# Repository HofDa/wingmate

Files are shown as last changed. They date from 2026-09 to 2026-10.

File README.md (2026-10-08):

# Bee × Fly Connectome MVP

Lokaler Forschungsprototyp für Wildbienen-ID aus **Wing Interference Patterns (WIP)** und **Flügeladerung**.

**Benutzerhandbuch:** [docs/Benutzerhandbuch.md](docs/Benutzerhandbuch.md) – Bedienung Schritt für Schritt, Rig, Landmarken, Training, Fehlerbehebung.
**Modellentwicklung:** [docs/model-development.md](docs/model-development.md) – tierbasierte Auswertung, Distanzkalibrierung und unabhängige Tests.
**Optionales Startmodell:** [models/bombus-starter/README.md](models/bombus-starter/README.md) – Landmarken-LDA für drei Bombus-Arten, numerische Referenzdaten und ODbL-Zitation.
**Aufnahme-Rig zum Drucken:** [rig/README.md](rig/README.md) – parametrisches OpenSCAD-Modell, STL, Teileliste, Montage.

## Pipeline

1. Venationsbild und optional WIP desselben Vorderflügels, mit dokumentierter QC
2. Flügelmerkmale und optionale manuelle Landmarken im passenden anatomischen Schema
3. Ein Referenzprototyp pro Tier aus seinen unterschiedlichen Flügelansichten
4. Standard: Procrustes/PCA/LDA mit Landmarken, sonst Distanz-kNN auf standardisierten Merkmalen
5. Separate Tier-Kalibrierung anhand von Merkmalsdistanzen; live nur explorative Typikalität
6. Cosine-kNN, FlyHash und Random Walk als Entwicklungsvergleiche
7. Abschlusstest an unabhängigen Tieren und ungesehenen Taxa außerhalb der Entwicklung

## Start

Für ES-Module und Web Worker einen lokalen HTTP-Server im Projektordner starten:

```bash
python -m http.server 8000
```

Dann `http://localhost:8000` öffnen.

## GitHub Pages

Die veröffentlichte App: **https://hofda.github.io/wingmate/**.

Der Workflow `.github/workflows/pages.yml` testet bei jedem Push auf `master` die Anwendung, erstellt das statische `_site`-Artefakt und veröffentlicht es über GitHub Pages. In den Repository-Einstellungen ist **Pages → Source → GitHub Actions** erforderlich. Der Workflow kann auch manuell gestartet werden.

`npm run build:pages` erstellt das Artefakt lokal in einem leeren `_site`-Verzeichnis. Es enthält die Laufzeitdateien und Icons; Testdatensätze, Entwicklerwerkzeuge und lokale Zertifikate werden nicht als Website veröffentlicht. Die Service-Worker-Version wird aus dem Inhalt des Artefakts erzeugt, damit geänderte Deployments automatisch einen neuen Offline-Cache erhalten. `PWA_SITE_ROOT=_site node scripts/pwa-smoke.cjs` prüft das fertige Artefakt inklusive Unterverzeichnis-Hosting und Offline-Nutzung.

Die Online-App speichert ihre Referenzen und Exemplare separat von `localhost`, da Browserspeicher an die Herkunft gebunden ist. Referenzen bei Bedarf lokal exportieren und in der veröffentlichten App importieren.

Für das **Smartphone** (Kamera braucht HTTPS) im selben WLAN:

```bash
npm run serve:https     # druckt https://<LAN-IP>:8443; Zertifikatswarnung einmal bestätigen
```

## Bedienung

Die App hat vier Bereiche (unten am Handy, oben am Desktop):

- **Exemplar** – Venation (und optional WIP) per **Foto wählen** (am Handy: Kamera oder Galerie)
  oder **Live-Kamera** laden, dann unter **Prüfen & Landmarken** Maske und Orientierung prüfen
  (*Um 180° drehen*, *Spiegeln*, *Standard geprüft*) und Landmarken setzen. Seltenes liegt
  eingeklappt unter *Maske korrigieren*, *Export & Metadaten* und *Weitere Aktionen*.
- **Ergebnis** – Bestimmung (Ähnlichkeitsgraph, Procrustes + LDA, offene Menge); Einbettung und
  Random Walk eingeklappt.
- **Referenzen** – Sammlung (Export/Import), Live-Prüfung und **Modell trainieren**.
- **Einstellungen** – Aufnahme-Rig, Rechenraum/FlyWire, App-Installation, Methodik.

Die Leiste am unteren Rand zeigt für das aktuelle Exemplar den Stand (Bild · Geprüft · Landmarken)
und genau den nächsten Schritt: **Freigeben**, danach **Bestimmen** oder **Als Referenz …**
(Art, Exemplar-ID, Geschlecht, Serie/Fundort).

## Als PWA installieren und offline nutzen

Die App enthält ein Web-App-Manifest, Installationsicons und einen Service Worker. Nach dem ersten vollständigen Online-Aufruf meldet die Leiste **Offline bereit**. Danach funktionieren App-Start, lokale Bildverarbeitung, Klassifikation und Markov-Walks auch ohne Netzwerk. Referenzen bleiben im bestehenden `localStorage`, archivierte Exemplare in IndexedDB. Die Installation migriert keine Daten zwischen Browsern oder Geräten; Referenzen weiterhin regelmäßig exportieren.

- Desktop/Android: **App installieren** anklicken, sobald der Browser die Installation anbietet; alternativ das Browsermenü verwenden.
- iPhone/iPad: **Teilen → Zum Home-Bildschirm** verwenden.
- Für Geräte im Netzwerk und öffentliche Bereitstellung **HTTPS** verwenden. `http://localhost:8000` genügt für lokale Entwicklung; eine unverschlüsselte LAN-IP genügt nicht für den Service Worker.
- Die Dateien können ohne Build-Schritt auch in einem Unterverzeichnis bereitgestellt werden. Manifest, Start-URL und Cache sind relativ zum App-Verzeichnis.

Neue Versionen werden im Hintergrund vollständig geladen. **Update laden** aktiviert die neue Version und lädt die Seite neu; vorher ungespeicherte Arbeit sichern. Ohne diesen Klick wartet ein Update, bis alle App-Fenster geschlossen sind. Gespeicherte Referenzen und Exemplare werden bei Updates nicht gelöscht. Nur die aufgelisteten App-Dateien werden gecacht; große Testdaten und importierte Graphdateien sind nicht Teil des Offline-Caches. Importierte Graphen und ungespeicherte Bilder müssen nach einem Neustart wie bisher erneut geladen werden.

Bei Änderungen an App-Dateien die `VERSION` in `sw.js` erhöhen und die vollständige Anwendung gemeinsam veröffentlichen. Neue Laufzeitmodule in `APP_FILES` aufnehmen. `sw.js` sollte vom Hosting ohne langfristigen HTTP-Cache ausgeliefert werden.

Prüfungen: `npm test`; mit installiertem Playwright und Chrome zusätzlich `node scripts/pwa-smoke.cjs` für Installierbarkeit, Offline-Reload, Worker, lokale Speicherung, Updates und Hosting im Unterverzeichnis. `node scripts/generate-pwa-icons.cjs` erzeugt die PNG-Icons aus `icons/wing.svg` erneut. Beide Browser-Skripte unterstützen `CHROME_PATH` für einen anderen Chrome-Pfad.

Installationsvoraussetzungen: [MDN – Making PWAs installable](https://developer.mozilla.org/en-US/docs/Web/Progressive_web_apps/Guides/Making_PWAs_installable).

Alle Bilder und Referenzen bleiben lokal. Referenzen werden im Browser-`localStorage` gespeichert und können als JSON exportiert werden.

Nach einer Klassifikation erklärt **Wie entsteht das Ergebnis? · Markov-Kette** die Berechnung. Mit **Abspielen**, **Zurück**, **Weiter**, **Zum Start**, **Zum Ergebnis** und dem Schrittregler lassen sich die Schritte 0–40 untersuchen. Drei Kennzahlen zeigen die Wahrscheinlichkeit beim eigenen Exemplar, bei den Referenzen und den seit dem letzten Schritt verschobenen Anteil. Die Artentabelle trennt die rohe Wahrscheinlichkeit von den nach Referenzzahl ausgeglichenen Ähnlichkeitsscores; die Scores des letzten Schritts entsprechen den Random-Walk-Balken im Ergebnis.

Im Graphen bleiben Positionen und Farben während der Wiedergabe gleich. Ein Klick auf einen Knoten (oder Tab und Enter) zeigt seine Übergangschancen einschließlich des 20-%-Rücksprungs. **Beispielpfad anzeigen** schaltet einen reproduzierbaren simulierten Weg ein: Orange zeigt den Weg, gestrichelt einen Rücksprung. Dieser einzelne Weg bestimmt nicht die berechnete Verteilung. Bei großen Sammlungen zeigt der Graph bis zu 25 Knoten am Desktop bzw. 13 auf schmalen Ansichten; **Alle Knoten · genaue Werte** enthält sämtliche Knoten, Wahrscheinlichkeiten und Änderungen in Prozentpunkten. Änderungen an Eingaben, Referenzen oder Reservoir-Einstellungen setzen die Ansicht zurück. Dargestellt wird der Klassifikationsgraph, nicht die interne FlyWire-Propagation.

## Step 0 · Smartphone-Aufnahme & Rig (rig-profile-1)

**Live-Kamera** an einem Bildfeld (`imaging/camera.js`) nimmt direkt mit der Rückkamera auf: Live-Vorschau mit
Platzierungsrahmen (Basis links, Spitze rechts, anterior oben), Fokus-, Überbelichtungs- und
Rig-Abweichungsanzeige, Mittelung über 1–16 Frames (Rauschen ∝ 1/√N) und verlustfreie PNG-Übergabe
an die QC. Aufnahmemetadaten (Frames, Rauschen, Kameraeinstellungen, Rig-ID) werden mitarchiviert.

- **Android + Chrome:** Fokus, Belichtung, Weißabgleich, ISO, Zoom und Taschenlampe werden – soweit
  die Kamera sie anbietet – nach dem Einpendeln mit **Aktuelle Einstellungen fixieren** gesperrt, im
  Rig gespeichert und beim nächsten Start automatisch mit exakt derselben Auflösung wieder angewendet.
- **iPhone (Safari):** Web-Seiten erhalten keine manuelle Kamerasteuerung. Live-Aufnahme funktioniert,
  aber mit Automatik; alternativ **Foto wählen** → Kamera-App (volle Auflösung, dort AE/AF-Sperre
  durch langes Tippen). Die Driftprüfung meldet dann abweichende Belichtung. iOS wechselt im
  Nahbereich teils automatisch das Objektiv; das verändert Maßstab und Licht – Profil erkennt das
  nur über Drift/Größe, daher Makro-Vorsatz fest auf die Hauptkamera.

### Rig kalibrieren

Unter **Rig kalibrieren** im Live-Kamera-Bereich (oder *Einstellungen → Mit der Live-Kamera kalibrieren*), mit montiertem Rig, eingeschaltetem Licht und fixierter Kamera:

1. **Venation-Hintergrund** – leerer Objektträger im Durchlicht (16 Frames gemittelt).
2. **WIP-Hintergrund** – leer, schwarzer Hintergrund, Auflicht.
3. **WIP-Graukarte** (optional) – neutrale Graukarte an der Flügelposition, Auflicht.
4. **Maßstab** (optional) – Lineal/Objektmikrometer an der Flügelposition, zwei Punkte anklicken, mm eingeben.

Das Profil (`imaging/rig.js`, IndexedDB, als JSON export-/importierbar) wird angewendet, wenn die
Bildgröße exakt passt; sonst verarbeitet die QC ohne Korrektur und sagt warum. Mit Profil:

- **Flat-Field-Korrektur** `out = in × Ziel / Beleuchtung(x,y,Kanal)` aus dem geglätteten leeren
  Durchlichtbild bzw. der Graukarte: entfernt Vignettierung, ungleichmäßiges Licht und Farbstich
  (Referenz wird neutralgrau). Gesättigte Sensorwerte bleiben gesättigt. Die Originaldatei wird
  unverändert archiviert; die Korrektur steht in `radiometricCorrection`.
- **Hintergrundmodell pro Pixel** für die Segmentierung statt einer Randfarbe; statischer Staub auf
  Glas/Diffusor hebt sich auf, die Schwelle folgt dem gemessenen Rauschen.
- **Driftprüfung** (Randband gegen Profil): verschobenes Rig oder anderes Licht → REVIEW und
  Rückfall auf die Randfarben-Segmentierung statt eines stillen Fehlers.
- **Absolute Größe**: Mit Maßstab und ohne Randkontakt speichert `metricSize` Flügellänge (mm) und
  -fläche (mm²); der Klassifikator nutzt sie als Block `size` (log), sobald alle Referenzen sie haben.
  Die Normalisierung auf 1024 × 512 entfernt Größe weiterhin.
- Unabhängig vom Rig: Sättigung im Flügel (> 0,5 %) → REVIEW; Schärfe (Laplace-Varianz) wird gespeichert.

In einer synthetischen Prüfung (starke Vignettierung, Farbstich, Staubfleck am Flügelrand) steigt die
Masken-IoU mit Profil auf > 0,95 und liegt deutlich über der Randfarben-Segmentierung
(`tests/rig.test.js`). Das ist ein Modelltest, keine Validierung an echten Rig-Aufnahmen.

### Hinweise für den Aufsatz

- Flügel flach zwischen Objektträger und Deckglas (ein Tropfen 70 % Ethanol hilft beim Glätten) in
  einem festen Schlitz auf Fokusebene; Aufnahme immer derselben Seite bzw. Spiegelung in der QC.
- Venation: gleichmäßiges, diffuses Durchlicht (LED-Panel + Opal-Diffusor), Konstantstrom-LEDs ohne
  PWM – PWM erzeugt mit dem Rolling Shutter Streifen, die keine Flat-Field-Korrektur entfernt.
- WIP: lichtschluckender schwarzer Untergrund (Velours/Flock), Auflicht unter festem Winkel; WIP-Farben
  hängen von Licht- und Blickwinkel ab, daher beides mechanisch fixieren. Gehäuse geschlossen halten,
  damit kein Umgebungslicht einfällt.
- Hohe Farbwiedergabe (CRI ≥ 90) und nach Wechsel von Lampe, Diffusor, Vorsatzlinse oder Telefon
  neu kalibrieren. Die Rig-Abweichung in der Vorschau zeigt, wann das nötig ist.

## Landmarken setzen (Procrustes + LDA)

In der QC-Karte des Venation-Bildes (ohne Venation: WIP) öffnet **Landmarken** den Editor
(`imaging/landmark-ui.js`, Schema/Koordinaten in `classifier/landmarks.js`):

- **Tippen/Klicken** setzt die aktuelle Landmarke und springt zur nächsten offenen. Ein Punkt wird
  nur verschoben, wenn man ihn *zieht* – so lassen sich eng benachbarte Landmarken (1/2, 16/17)
  setzen. Ein Klick auf einen anderen Punkt wählt ihn aus.
- **Lupe**: zeigt die *Originalpixel* (volle Kameraauflösung) in Standardorientierung, 6-fach.
  Ein Klick dort verfeinert die gewählte Landmarke und geht weiter – grob tippen, fein setzen,
  auch am Handy. Pfeiltasten verschieben um 0,25 px (Shift: 2 px), `n`/`p` wechseln, Strg+Z.
- **Führung**: Übersicht des mittleren Musters mit der aktuellen Nummer. Ab 2 Punkten wird es an
  die gesetzten Punkte angepasst und zeigt gestrichelt, wo die nächsten erwartet werden. Ab 4
  Punkten werden starke Abweichungen orange markiert (typisch: vertauschte Nummern).
- **Fehlt (beschädigt)** markiert eine nicht bestimmbare Landmarke; unvollständige Sätze gehen
  nicht in die Klassifikation ein.
- Gespeichert wird in **Originalpixeln**; die Punkte bleiben bei Drehen/Spiegeln/Schwelle/Neuberechnung
  gültig. Ins Archiv (IndexedDB), in den JSON-Export und als **Landmarken als CSV** (*Weitere Aktionen*)
  (`file,x1,y1,…`, y nach unten; `landmarksCsv(…, {yUp: true})` für die Konvention des Datensatzes)
  für MorphoJ/geomorph. Änderungen nach **Freigeben** heben die Freigabe auf.

**Schema** `bombus-19`: die 19 Landmarken des Molasy-&-Tofilski-Datensatzes (IdentiFly-Nummerierung).
Die Führung ist das Procrustes-Mittel aller 814 Flügel, nachgerechnet in `tests/landmarks.test.js`.
Achtung: die CSV des Datensatzes zählt **y von unten** (auf den 18 lokalen Bildern liegen die Punkte
nur so auf Aderkreuzungen). Für Gattungen mit anderer Aderung (z. B. 2 Submarginalzellen) ist ein
eigenes Schema nötig; Blöcke verschiedener Schemata werden nie verglichen.

**Klassifikation**: Vollständige Landmarken eines *orientierungsbestätigten* Bildes werden zum Block
`landmarks` (Standardansicht, damit linke und rechte Flügel nach dem Spiegeln vergleichbar sind –
Procrustes entfernt keine Spiegelung). Haben alle Referenzen Landmarken desselben Schemas, zeigt die
Ausgabe zusätzlich **Procrustes + LDA**: GPA (nur auf Trainingsreferenzen; Abfrage an feste Mittelform angepasst) → Hauptkomponenten
(bei wenigen Exemplaren höchstens (n − Taxa)/2) → LDA mit Ledoit–Wolf-Schrumpfung →
Wahrscheinlichkeiten per gruppiertem Leave-one-out **temperaturkalibriert**. Die Validierung listet
die LDA-Zeile zuerst. LDA wählt immer ein bekanntes Taxon; für Unbekannte gilt das konforme Set.

Die Temperatur wird nur aus den Trainingsgruppen geschätzt. Auch in dieser inneren
Validierung wird die Procrustes-Ausrichtung neu angepasst. Entwicklungswerte ersetzen
keinen Test an unabhängigen Tieren oder eine Prüfung der Erkennung unbekannter Arten.

## Training (Modell einfrieren)

Unter **Referenzen → Modell trainieren** (`classifier/model.js`, läuft im Worker):

1. **Bereitschaft** je Art: Exemplare, Flügel, Landmarken, Geschlecht, Serien; Warnung bei
   < 10 Exemplaren, nur einem Geschlecht oder nur einer Serie/Fundort.
2. **Trainieren** reserviert je Taxon standardmäßig 20 % der unabhängigen Tiere für die
   Kalibrierung (mindestens zwei Tiere bleiben im Training). Diese Tiere beeinflussen keine
   Anpassung von Ausrichtung, Standardisierung, PCA oder LDA. Ein fester FlyHash lernt keine
   Bildmerkmale. Fehlende Modalitäten erfordern eine explizite Wahl des Eingabemodus.
3. **Bewertung** aller Verfahren mit denselben stratifizierten, nach Exemplar gruppierten
   5 Falten, mit neu angepasster Pipeline pro Trainingsfold. Landmarken-LDA ist Standard,
   sonst Distanz-kNN; andere Verfahren bleiben Vergleiche. Jedes Tier zählt einmal, Flügelwerte
   stehen getrennt im Export. Die Intervalle resampeln Tiere. Das sind Entwicklungswerte, kein unabhängiger Abschlusstest. Haben alle Referenzen eine Serie,
   zusätzlich **Transfer auf ungesehene Serien** (jeweils eine Serie zurückgehalten).
4. Das Modell wird gespeichert (IndexedDB), ist exportier-/importierbar (`wingmate-model-3`,
   JSON) und bestimmt, solange aktiv, alle neuen Tiere; neue Flügel richtet es per Procrustes an
   der gespeicherten Mittelform aus. Geänderte Referenzen werden angezeigt – dann neu trainieren.

Serien/Geschlecht müssen die spätere Anwendung abdecken. Stabile Exemplar-IDs sind Pflicht,
damit linke/rechte Flügel eines Tieres im selben Split bleiben. Alte Modelle benötigen neues
Training. Bildreferenzen aus `wing-features-1` / `wing-normalizer-0.2` müssen aus den archivierten
Originalen neu verarbeitet werden; Dateien und Archive werden nicht gelöscht.

## Echte FlyWire-Daten

Codex bietet für FlyWire-FAFB öffentliche Daten-Downloads und exportierbare Connectivity-Tabellen. Für den Browser sollte nicht das komplette Netzwerk geladen werden, sondern ein Subgraph (z. B. Mushroom Body / Kenyon-cell-bezogene Zellen).

1. Connectivity-CSV aus Codex/FlyWire exportieren.
2. Falls gewünscht, zusätzlich eine Liste erlaubter Root IDs erstellen.
3. CSV kompakt konvertieren:

```bash
python prepare_flywire.py connections.csv flywire-subgraph.json \
  --source-col pre_root_id \
  --target-col post_root_id \
  --weight-col syn_count \
  --min-weight 5 \
  --max-nodes 20000 \
  --max-edges 150000
```

Falls die CSV andere Spaltennamen verwendet, diese per `--source-col`, `--target-col`, `--weight-col` angeben.

Danach `flywire-subgraph.json` im UI unter **FlyWire-Subgraph importieren** laden.

## Step 2 · Klassifikation (wing-features-2)

Code in `classifier/` (reine ES-Module, in Node getestet), UI in `app.js`, Markov-Ansicht in `walk.js`.

1. **Merkmale** (`features.js`) auf dem auf 256 × 128 verkleinerten Normalbild, mit separater
   Innenmaske gegen interpolierte Konturränder. Gleichförmige Membranen erzeugen keine Adermerkmale:
   Umrissprofil (66), Venation als HOG-artige Orientierungshistogramme + relative Dunkelheit
   je 8 × 4-Zelle ohne Konturrand (288), WIP als CIELAB je Zelle + chroma-gewichtetes
   Farbtonhistogramm (112). Keine Farbkorrektur; Aufnahmebedingungen müssen fix sein.
2. **Standardisierung** auf einem Prototyp je Trainingstier (z-Score, jeder Block gleich gewichtet).
   Identische Wiederholungen werden entfernt, unterschiedliche Ansichten innerhalb eines Tieres gemittelt.
   Referenzen speichern **Merkmale, keine Embeddings**; bei jeder Klassifikation wird
   alles mit denselben Einstellungen neu eingebettet (alte v1-Embedding-Referenzen werden
   erkannt und nicht verwendet).
3. **Reservoir** (`embedding.js`): FlyHash nach Dasgupta et al. 2017 (zentrieren, dünne
   *binäre* Projektion mit Fan-in 6, Top-5 %-Winner-take-all), dichte Zufallsprojektion als
   LSH-Kontrolle, „kein Reservoir“, optional FlyWire-Graph (explorativ: Merkmal→Neuron-
   Zuordnung ist willkürlich).
4. **Random Walk with Restart** auf dem kNN-Graphen (k = 7, Restart 0,2, 40 Schritte).
   Die Masse je Taxon wird durch dessen Referenzzahl geteilt, sonst gewinnt das häufigste
   Taxon. `rwrTransitions` liefert dieselbe Übergangsmatrix an die Markov-Ansicht; ein Test
   prüft, dass `traceWalk` exakt die bewertete Verteilung reproduziert.
5. **Open-set** im eingefrorenen Modell: label-bedingte Split-Kalibrierung gegen getrennte
   Tiere. Der Score misst euklidische Distanzen in den standardisierten Merkmalen ohne
   L2-Normalisierung; damit bleiben extreme Abweichungen entlang bekannter Richtungen sichtbar.
   Mehrere Flügel eines Kalibrierungstieres ergeben nur einen (maximalen) Score; auch die
   Nachbarschaft zählt Tiere, nicht doppelte Flügel. Bei ε = 0,1 sind mindestens neun unabhängige
   **Kalibrierungstiere je Taxon** für die nötige p-Wert-Auflösung erforderlich. Darunter meldet
   die UI unzureichende Kalibrierung. Live-Jackknife bleibt ausdrücklich explorativ und darf keine
   kalibrierte Abdeckung oder belastbare Erkennung unbekannter Arten behaupten.
6. **Validierung** im UI: gruppierte Kreuzvalidierung mit vollständiger Anpassung innerhalb der
   Trainingsgruppen, aktueller Modus gegen kNN und „kein Reservoir“. Bilderpaare erfordern eine
   Bestätigung desselben Flügels und der inneren Korrespondenz. QC-Hinweise benötigen eine
   dokumentierte Freigabebegründung; ein plausibler Umriss allein belegt keine brauchbare Aderung.

### Benchmark auf realen Daten

`node scripts/landmark-benchmark.js --out test-data/landmark-benchmark.json` nutzt
814 Landmarkdatensätze (423 Exemplare, 3 *Bombus*-Arten). Version 3 prüft die
**Klassifikationsstufe** mit Tierprototypen, Tierergebnissen und Bootstrap-Intervallen in
identischen fünf gruppierten Folds, getrennter Tier-Kalibrierung und
Procrustes/Skalierung/PCA/LDA ausschließlich im Trainingsfold. Die innere Temperaturkalibrierung
hält ebenfalls ganze Tiere zurück und passt die Ausrichtung neu an.

Die frühere Tabelle mit globaler Procrustes-/z-Score-Anpassung wurde entfernt. Die aktuellen
Messwerte und das genaue Protokoll stehen in `test-data/landmark-benchmark.json`. Sie belegen
keine Genauigkeit der vollständigen Bildpipeline und keinen Nutzen echter gepaarter Bee-WIP-Daten.
Der [Auditbericht](docs/pipeline-audit.md) dokumentiert die verbleibenden Daten- und Forschungsaufgaben.

### Tests

```bash
npm test                                           # Node: Normalisierung, Klassifikation, Walk
NODE_PATH=… node scripts/markov-ui-e2e.cjs        # Browser: Markov-Anzeige, Daten, Steuerung, Desktop/Handy
NODE_PATH=… node scripts/classifier-e2e.cjs        # Browser: QC → Referenzen → Klassifikation → Walk → Validierung
NODE_PATH=… node scripts/camera-e2e.cjs            # Browser, Fake-Kamera: Rig kalibrieren → Neustart → Aufnahme → QC
NODE_PATH=… node scripts/landmark-e2e.cjs          # Browser, 7 reale Flügel: 19 Landmarken per UI, Lupe, LDA, CSV
NODE_PATH=… node scripts/training-e2e.cjs          # Browser: Training im Worker, Bericht, Modell bestimmen, Export/Import
```

Der Landmarken-E2E klickt die publizierten Landmarken durch die Oberfläche, prüft den exakten
Koordinatenweg (Klick → Standardansicht → Originalpixel, auch mit Flip/Mirror), dass die Punkte
auf Aderkreuzungen des angezeigten Bildes liegen, sowie LDA-Ergebnis, Validierung und CSV-Export.
Er misst nicht, wie genau ein Mensch klickt.

Der Klassifikations-E2E prüft Verdrahtung und Konsistenz auf den Entwicklungsbildern, keine
Genauigkeit. Der Kamera-E2E erzeugt synthetische Y4M-Videos (leeres Rig / Rig mit Flügel inkl.
Vignettierung, Farbstich, Rauschen) und prüft Flat-Field, Hintergrundmodell, Drift, Masken-IoU > 0,95
und die mm-Länge. Beide brauchen einen Server auf `127.0.0.1:8000`.

## Was noch nicht „Publikationsniveau“ ist

- Die WIP- und Aderungsfeatures sind bewusst leichtgewichtig und interpretierbar. Für ernsthafte Taxonomie sollten CNN/ViT-Embeddings bzw. automatische Landmark-Erkennung ergänzt werden.
- Das eingefrorene Modell nutzt getrennte Kalibrierungstiere; die Live-Bestimmung bleibt heuristisch. Die Erkennung unbekannter Arten braucht einen separaten Test mit zurückgehaltenen Taxa.
- Die Mushroom-Body-Variante ist biologisch inspiriert; nur der importierte Graph verwendet reale FlyWire-Konnektivität.
- Vor einer wissenschaftlichen Aussage muss gegen starke Baselines verglichen werden: Procrustes+LDA/SVM, kNN, direkte CNN/ViT-Klassifikation, randomisiertes Reservoir und randomisierte FlyWire-Topologie.

## Sinnvoller erster Datensatz

Für einen Proof of Concept eher 5–10 gut abgesicherte Arten, mehrere Individuen pro Art, standardisierte WIP-Aufnahme und Durchlichtaufnahme desselben Flügels. Danach schwierige Artgruppen hinzufügen.

## Step 1 · Flügelnormalisierung (wing-normalizer-0.3)

Start jetzt **über HTTP**, da ES-Module und Web Worker verwendet werden:

```bash
npm run serve
# http://localhost:8000
npm test
```

Venation und/oder WIP hineinziehen. Die QC zeigt Original, echte Binärmaske,
normalisiertes Bild und Kontur/PCA/Schwerpunkt/Basis-/Spitzenkandidaten.
*Um 180° drehen* und *Spiegeln* korrigieren die Orientierung. Originalseite separat
angeben; vor *Freigeben* bestätigen: Basis links, Spitze rechts, Vorderrand oben.
Schwelle ändern oder eine extern korrigierte Schwarzweißmaske importieren,
wenn die automatische Segmentierung nicht ausreicht. `Reset` verwirft die
Korrekturen, erhält aber die dokumentierte Originalseite.

*Freigeben* archiviert Originaldateien, Masken, normalisierte RGBA-Bilder und
Metadaten lokal in IndexedDB. `Letztes Exemplar öffnen` lädt sie erneut zur QC.
PNG- und JSON-Exporte sind portable Ergebnisse; Browserdaten können vom Benutzer
oder Browser gelöscht werden. JSON enthält auch die Analysemaske als binäre
Lauflängencodierung (beginnt mit Anzahl der Nullen). Feature-Referenzen enthalten
die Vorverarbeitungsversion, Transformationen und Archiv-ID. Alte Referenzen
werden nicht automatisch mit neuen Koordinaten verglichen.

### Verfahren und Koordinaten

- Deterministische Segmentierung auf höchstens 640 px langer Analyseachse:
  dominante Randfarbe, RGB-Abstand, morphologisches Schließen, Lochfüllung,
  größte plausible längliche Komponente. Keine rechteckige Ersatzmaske.
- PCA bestimmt die Längsachse; ein Querschnittsbreitenprofil vergleicht beide
  Enden. Dies ist eine **ungeprüfte Heuristik**, keine anatomische Garantie.
  `orientationConfidence` und `maskConfidence` sind Kategorien, keine
  statistischen Wahrscheinlichkeiten. Symmetrische/abgeschnittene Flügel prüfen.
- Standardcanvas 1024 × 512, mindestens 32 px Rand, Maskenschwerpunkt exakt bei
  (511.5, 255.5). Einheitliche Skalierung ohne Stretching. Die ausgewählte
  Analyseauflösung begrenzt die Konturgenauigkeit; Original-RGB bleibt erhalten.
- Matrizen: zeilenweise 3 × 3, Spaltenvektor `[x,y,1]`. Pixelzentren liegen bei
  ganzzahligen Koordinaten; Originalkoordinaten beziehen sich auf das durch den
  Browser decodierte, EXIF-orientierte Bild. `inverseTransformMatrix` führt zurück.
- RGB wird einmal direkt aus dem Original bilinear resampelt, die Maske per
  nearest-neighbor. Außerhalb der Maske ist Alpha 0. Keine Farbverbesserung,
  Weißabgleich, Histogrammänderung oder WIP-Klassifikation. Browser-Decodierung
  ist keine kontrollierte wissenschaftliche Farbkalibrierung; Originaldateien
  werden unverändert archiviert.
- `scale` ist Pixelnormalisierung, keine Körpergröße. `originalMetricScale`
  bleibt separat und standardmäßig `null`; die API kann z. B.
  `{micrometersPerPixel: 2.5, source: 'stage micrometer'}` erhalten.
- Flächen/Bounding Box in `maskQuality` sind ausdrücklich Analysepixel;
  `wingAreaOriginalPixels` rechnet die Fläche zurück. Originalmaße, Randkontakt,
  Fragmentierung, effektive Parameter und Version werden gespeichert.
- WIP wird über binäre Flügelform auf die normalisierte Venation registriert:
  begrenzte Rotation, uniforme Skalierung und Translation, keine Scherung oder
  nichtlineare Verformung. Registrierung speichert ihre eigene Matrix und die
  zusammengesetzte Original→Referenz-Matrix. Referenz und Moving müssen dasselbe
  Individuum und denselben Vorderflügel zeigen. Eine hohe Mask-IoU belegt keine
  genaue Übereinstimmung innerer Ader-Landmarks.

Die Rechenlogik liegt in `imaging/{segmentation,quality,orientation,normalization,
registration,pipeline,matrix}.js`, der Worker in `worker.js`, UI und Speicherung
in `qc-ui.js` / `storage.js`. Reservoir, FlyWire und Random-Walk-Verfahren wurden
für diesen Schritt nicht erweitert.

### Entwicklungsdaten und Validierung

Siehe [Datensatzdokumentation](test-data/README.md),
[Lizenzen](test-data/LICENSES.md), [Metadaten](test-data/metadata.json) und
[Benchmark](test-data/benchmark.json). 36 reale Aufnahmen/Publikationsausschnitte
sind lokal enthalten. Die ausgeschnittenen Panels sind **keine Rohaufnahmen**.
Viele Bilder enthalten angeschnittene Basen, Schäden, Text oder Hintergrund-
artefakte und sind ausdrücklich schwierige Fälle. Es handelt sich um einen
Entwicklungsdatensatz, keine unabhängige wissenschaftliche Validierung.

Die Node-Tests verwenden analytische Flügelformen und prüfen Rotation 0/25/90/180°,
Translation, Objekt- und Rasterauflösung, Hintergrundhelligkeit, Spiegelung,
Determinismus, Rücktransformation, Maskenkorrektur, Lochfüllung, Artefakte,
WIP-RGB-Erhalt und Registrierung.

Browserprüfungen benötigen Playwright und Chromium (nicht für den App-Betrieb):

```bash
# Bei Bedarf NODE_PATH auf eine vorhandene Playwright-Installation setzen.
node scripts/browser-benchmark.cjs
node scripts/real-invariance.cjs
```

Ein geeignetes reales, kontrolliertes Wildbienen-WIP/Venation-Paar ist derzeit
nicht enthalten. WIP-Farberhalt wird synthetisch geprüft; biologische Paar-
registrierung und vollautomatische Seiten-/Basisbestimmung bleiben zu validieren.
## Apis mellifera reference data

An optional [honeybee numeric collection](models/apis-source/README.md) now
ships alongside the Bombus starter: 29,043 source wings from 1,342 colonies in
ten countries, under [ODbL 1.0 with attribution](models/apis-source/NOTICE.md).
The adapted collection selects one wing per colony; unchanged source CSVs,
publisher checksums and an offline build recipe are included. Rebuild with
`npm run build:apis-references`. The training panel offers the collection download.
Its Nawrocka (2018) numbering differs from the Bombus guide, so this is reference
data pending a verified anatomical mapping, rather than a combined classifier.

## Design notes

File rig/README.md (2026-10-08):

# Wingmate-Rig – 3D-druckbarer Aufnahmeaufbau

Ein Kasten, auf den das iPhone gelegt wird: immer **gleicher Abstand**, **gleiches Licht**, **gleicher
Hintergrund**. Unten ein LED-Leuchtkasten (Durchlicht für die Aderung), darüber eine Schublade für
den Objektträger, eine dunkle Kammer und oben die Handyauflage. Für WIP gibt es eine schwarze
Schublade und einen (experimentellen) Lichtring um die Kamera.

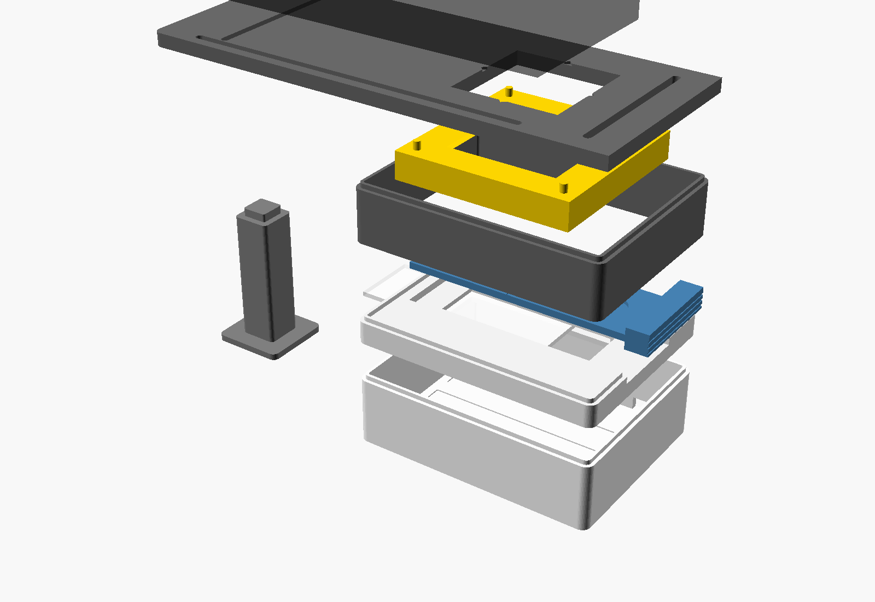
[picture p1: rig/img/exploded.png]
Explosionszeichnung


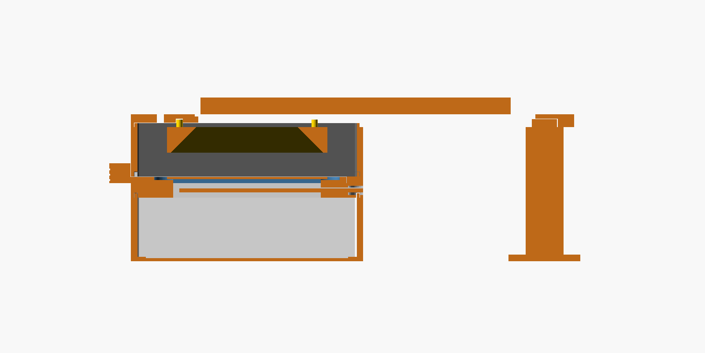
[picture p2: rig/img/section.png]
Schnitt: Lichtkasten, Diffusor, Schublade, Kammer, Lichtring, Auflage mit Handy, Stütze


Ausgelegt für: **iPhone mit eigenem Makromodus** (Ultraweitwinkel, fokussiert ab ca. 2 cm),
**COB-LED-Streifen + Diffusor**, **Druckbett 220 × 220 mm**. Alles ist parametrisch
(`wingmate-rig.scad`) und lässt sich im OpenSCAD-Customizer anpassen.

> **Stand:** entworfen, gerendert und auf Kollisionen geprüft (`check.sh`), aber **noch nicht
> gedruckt**. Zuerst die Passung testen (Abschnitt „Zuerst testen“).

---

## Teile drucken

Die fertigen STL liegen in `stl/`. Neu erzeugen: `./build.sh` (siehe „Anpassen“).

| Datei | Anzahl | Farbe | Lage im Drucker | Hinweise |
| --- | --- | --- | --- | --- |
| `base.stl` | 1 | **weiß** | Öffnung nach oben | Innen weiß = Reflektor. Rillen im Boden für 3 LED-Reihen. |
| `stage.stl` | 1 | **weiß** | Oberseite nach oben | Diffusorschlitz = 30-mm-Brücke: Lüfter 100 %. Optional Stützen im Schlitz (von der offenen Seite herausziehbar). |
| `carrier.stl` | 1 | **weiß** | flach | Schublade Durchlicht. Weiß, damit der sichtbare Rahmen nicht völlig schwarz ist (hilft der Kalibrierung). |
| `carrier_wip.stl` | 1 | **schwarz matt** | flach | Schublade WIP, Mulde für Flockfolie unter dem Objektträger. |
| `tower.stl` | 1 | **schwarz matt** | stehend | Dunkelkammer; Höhe ergibt sich aus dem Arbeitsabstand. |
| `deck.stl` | 1 | **schwarz** | Oberseite nach oben | 210 × 86 mm. Kamerafenster, 3 Schlitze für Anschläge, Aufnahme für die Stütze. |
| `leg.stl` | 1 | beliebig | stehend | Stütze unter dem überstehenden Ende. Nach Änderung von `spacer_count` neu drucken. |
| `stop.stl` | 3 | beliebig | Anlagefläche stehend | Handy-Anschläge. |
| `knob.stl` | 3 | beliebig | Sechskant oben | Rändelmutter mit M3-Mutterfalle (Mutter einpressen). |
| `ring.stl` | 1 | **weiß** | Stifte nach oben | *Experimentell* – WIP-Lichtring; Innenflächen 45°. |
| `spacer.stl` | 0–4 | schwarz | stehend | Je +5 mm Arbeitsabstand, zwischen Kammer und Auflage. |
| `diffuser.stl` | 0–1 | **weiß** | flach, 100 % Infill | Nur falls kein Opal-Acrylglas: gedruckter Diffusor (sichtbare Struktur möglich). |

Allgemein: PLA oder PETG, 0,2 mm Schicht, 3 Perimeter, 15–20 % Infill, keine Stützen nötig.
Gesamt ca. 150–200 g Filament. **Schwarz matt** für alles, was die Kamera außerhalb des Lichtfensters
sieht (Kammer, Auflage, WIP-Schublade); **weiß** für Lichtkasten, Bühne und Ring.

## Zukaufteile

| Teil | Menge | Hinweis |
| --- | --- | --- |
| COB-LED-Streifen **5 V USB**, neutralweiß **4000 K, CRI ≥ 90** | ~0,5 m | ca. 30 cm für den Lichtkasten (3 × 9 cm), ca. 20 cm für den Ring (4 × 4,5 cm). COB = durchgehender Lichtstrich, gleichmäßiger als Einzel-LEDs. |
| USB-Netzteil oder Powerbank | 1–2 | **Ohne Dimmer**: USB-Dimmer arbeiten meist mit PWM → Streifen im Bild. |
| Opal-Acrylglas (Milchglas) **87 × 30 × 2 mm** | 1 | Bester Diffusor; Baumarkt/Zuschnitt. Alternative: `diffuser.stl`. |
| Schwarze **Flockfolie** (Velours, selbstklebend) | 60 × 24 mm | In die Mulde der WIP-Schublade. |
| Objektträger 76 × 26 mm, Deckgläser 22 × 22 oder 24 × 50 mm | nach Bedarf | Flügel mit einem Tropfen **70 % Ethanol** flach legen, Deckglas auflegen. |
| M3 × 16 Schrauben, M3-Muttern, Unterlegscheiben | je 3 | Für die Anschläge. |
| Objektmikrometer oder Lineal-Objektträger (1 mm / 0,01 mm) | 1 | Für die mm-Kalibrierung. |
| Graukarte 18 % | 1 | Optional, für WIP-Farbkorrektur (auf 76 × 26 mm zuschneiden). |
| Litze, Lötkolben, Schrumpfschlauch | – | Für die Verbindung der LED-Abschnitte. |

## Elektrik

- **Lichtkasten:** COB-Streifen in drei Stücke à ~9 cm an den Schnittmarken teilen, in die drei
  Bodenrillen kleben (Kupferpads zur selben Seite). Die Reihen **parallel** verbinden (+ an +, − an −)
  und das Stück mit dem USB-Stecker behalten. Kabel durch die Aussparung hinten unten.
- **Ring (WIP):** vier Stücke à ~4,5 cm auf die schrägen Innenflächen kleben, parallel verbinden,
  eigenes USB-Kabel durch die Aussparung oben hinten in der Kammer.
- Umschalten = Stecker ziehen/stecken: **Durchlicht an, Ring aus** für Venation; **Ring an,
  Durchlicht aus** für WIP. Nie beides.

## Zusammenbau

1. Leuchtkasten (`base`) mit LEDs, darauf die Bühne (`stage`) – die Lippe rastet ein.
2. Diffusor von der Seite (−x, gegenüber dem Schubladengriff) in den Schlitz schieben, bis er bündig ist.
3. Dunkelkammer (`tower`) aufsetzen, ggf. Distanzrahmen (`spacer`).
4. Ring (`ring`) mit den vier Stiften von unten in die Auflage (`deck`) stecken.
5. M3-Schrauben von **unten** durch die Schlitze der Auflage, darauf Anschlag (`stop`) und
   Rändelmutter (`knob`). Schrauben über der Kammer vor dem Aufsetzen einsetzen.
6. Auflage aufsetzen, Stütze (`leg`) unter das überstehende Ende stecken.
7. Objektträger in die Schublade legen, Schublade bis zum Anschlag einschieben – der Griff dichtet
   die Öffnung gegen Licht ab.

## iPhone einrichten

1. Handy mit dem Display nach oben auf die Auflage legen, Kamera über dem Fenster.
2. Die **Ultraweitwinkel-Linse** (die das Makro macht) genau über die Mitte bringen: In Wingmate
   *Exemplar → Live-Kamera* öffnen; die Kerben am Fensterrand und die Mittelmarken der Schublade
   helfen. Dann die drei Anschläge an das Handy schieben und festdrehen. Ab jetzt liegt das Handy
   immer gleich.
3. In der Live-Kamera unter **Kamera** die rückseitige **Ultraweitwinkel-Kamera** wählen, falls
   angeboten. Die automatische Objektivumschaltung („Triple/Dual Camera“) verändert sonst Maßstab und
   Bild.
4. Schärfe prüfen: Die Anzeige **Fokus** sollte stabil hoch sein. Stellt Safari nicht scharf,
   einen Distanzrahmen einsetzen (+5 mm) und `leg` für `spacer_count = 1` neu drucken.

**Wichtig:** iPhone-Safari kann Fokus, Belichtung und Weißabgleich nicht sperren. Deshalb:
Umgebung konstant halten (Kasten geschlossen, gleiches Netzteil) und **immer mit der
Live-Kamera** aufnehmen – das Rig-Profil gilt nur für genau diese Auflösung. Fotos aus der
Kamera-App haben eine andere Auflösung; dafür greift die Rig-Korrektur nicht.

## In Wingmate kalibrieren (Pflicht)

Die Ultraweitwinkel-Kamera sieht bei 25 mm etwa 60 × 45 mm – mehr als der Objektträger. Im Bild
sind daher neben dem hellen Lichtfenster auch Teile der Schublade zu sehen. Die Flügelerkennung
ohne Rig-Profil (Hintergrund = Bildrand) würde daran scheitern; mit Profil vergleicht Wingmate jedes
Pixel mit dem leeren Rig, und der Rahmen stört nicht.

*Einstellungen → Aufnahme-Rig → Mit der Live-Kamera kalibrieren* (siehe Benutzerhandbuch,
Kapitel 3):

1. **Venation-Hintergrund:** leerer Objektträger in der weißen Schublade, Durchlicht an.
2. **WIP-Hintergrund:** leerer Objektträger in der schwarzen Schublade, Ring an.
3. **WIP-Graukarte** (optional): Graukarte in der schwarzen Schublade, Ring an.
4. **Maßstab:** Objektmikrometer in der Schublade; zwei Teilstriche anklicken, Abstand in mm.
5. Speichern. Bei jeder Änderung an Licht, Diffusor, Distanz oder Telefon neu kalibrieren.

## Zuerst testen

Vor dem kompletten Druck (ca. 2 h):

1. `stage.stl` und `carrier.stl` drucken. Schublade muss leicht gleiten, Objektträger locker in der
   Mulde liegen, Diffusor in den Schlitz passen. Zu stramm/locker → `tol` ändern (Standard 0,25 mm).
2. `tower.stl` auf `stage.stl` setzen: Die Lippe soll ohne Kraft einrasten.
3. Handy provisorisch auf der Kammer: Stellt die Live-Kamera bei 25 mm scharf?

## WIP-Beleuchtung (experimentell)

WIP-Farben entstehen durch Interferenz und hängen stark vom Licht- und Blickwinkel ab
(Literatur: schwarzer Untergrund, helles, gerichtetes Licht). Bei 25 mm Arbeitsabstand trifft das
Licht des Rings unter etwa 60° zur Senkrechten auf den Flügel. Ob das für Ihre Arten genügend Farbe
zeigt, muss getestet werden. Stellschrauben: größerer Arbeitsabstand (Distanzrahmen) = Licht steiler
von oben, näher an der Kameraachse; Ringhöhe im Code (`ring`, h = 12); Diffusion (weißes Papier vor
den LEDs). Venation (Landmarken) hat Vorrang; WIP ist ein Zusatz.

## Anpassen

Im OpenSCAD-Customizer (Fenster → Customizer) oder per Kommandozeile:

| Parameter | Standard | Bedeutung |
| --- | --- | --- |
| `working_distance` | 25 | Linse → Flügel in mm (bestimmt die Kammerhöhe). |
| `spacer_count` | 0 | Anzahl 5-mm-Distanzrahmen; danach `leg` neu drucken. |
| `camera_bump` | 4,5 | Wie weit das Kameramodul hervorsteht (iPhone Pro: ca. 4–5 mm; messen!). |
| `window_size` | 46 × 46 | Kamerafenster; muss das ganze Kameramodul aufnehmen. |
| `deck_extension` | 100 | Überstand der Auflage für den Handykörper. |
| `tol` | 0,25 | Spiel für Passungen. |
| `slide`, `diffuser`, `light_window` | 76 × 26 × 1 · 87 × 30 × 2 · 70 × 22 | Objektträger, Diffusor, Lichtfenster. |

```bash
./build.sh -D working_distance=30 -D camera_bump=4   # alle STL + Vorschaubilder
./check.sh -D working_distance=30                    # Kollisionsprüfung aller Teile
openscad -D 'part="stage"' -o stage.stl wingmate-rig.scad   # ein Teil
```

`build.sh` und `check.sh` verwenden `openscad` aus dem Pfad oder `OPENSCAD=/pfad/zu/openscad`.
Die Konsole zeigt `RIG … effective_working_distance=… total_height=…` zur Kontrolle.

## Bekannte Grenzen

- Nicht gedruckt getestet – Passungen und Lichtdichtheit am ersten Druck prüfen.
- Handypositionierung über Anschläge statt modellspezifischer Halterung: einmal einstellen, dann
  wiederholbar. Für ein bestimmtes Modell lässt sich eine passgenaue Schale ergänzen.
- WIP-Ring: Winkel und Helligkeit unerprobt.
- Maßstab und Rig-Profil gelten für eine Konfiguration; nach jeder Änderung neu kalibrieren.

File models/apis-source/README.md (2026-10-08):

# Apis mellifera numeric reference collection

Pinned source: [Machlowska et al. (2026), version 2](https://doi.org/10.5281/zenodo.18845767).
The source contains 29,043 worker fore wings from 1,342 colony samples across
BY, DE, ES, FR, GB, IE, LT, NL, NO and PL. This package includes only numeric
landmarks and metadata, with unchanged original CSV files in `originals/`.
No photographs or journal figures are included. See [NOTICE.md](NOTICE.md).

`references.json` contains one wing per colony, selected by the smallest
SHA-256 of `wingmate-apis-v1:<wing filename>`. All 1,342 colonies remain.
It preserves the original 38 coordinates (x1,y1,...,x19,y19), in pixels with
origin lower-left and y increasing upwards. `landmarkScheme` is explicitly
`apis-nawrocka-2018-19`, and `splitGroup` is the country-qualified colony ID.
This format is a published landmark collection, not an app feature export,
personal reference import or installable classifier.

Reproduce offline with `npm run build:apis-references`. The build verifies all
20 CSVs against the archived publisher MD5 manifest and records SHA-256 hashes
and attribution in the adapted collection. To fetch verified numeric originals,
run `python3 scripts/fetch-apis-data.py` (network required). Both recipes are
in the [source repository](https://github.com/HofDa/wingmate/tree/master/scripts).

Two German raw filenames (`DE-0003-14.dw.png`, `DE-0003-4.dw.png`) do not match
their metadata counterparts (which have `_0` suffixes). These two joins are
excluded without guessing a correction; `excludedJoins` records the discrepancy.
Other exact joins, finite integer coordinates and country-qualified colony IDs
are checked. Unexpected discrepancies fail the build.

The Apis and Bombus figures use different landmark numbering. Their anatomical
mapping must be independently verified before a shared feature adapter and
combined model can be built. A single named species provides no negative classes
for species discrimination. No subspecies labels, individual worker pairing or
sex distinctions beyond the publisher's worker description are inferred.

For future modelling, keep colonies together in training/calibration/test splits
and perform a country or acquisition holdout. Multiple wings within a colony are
not independent animals. The selected wings are an explicit colony-level sample,
not a prevalence estimate or an independently validated classifier. Combining
Apis from this study with Bombus from another also confounds species and source:
high internal accuracy alone would not establish acquisition transfer.

The app makes the small adapted collection and notices available offline. The
full unchanged numeric originals and archived record ship in the repository/site
but are not added to the app's offline cache.

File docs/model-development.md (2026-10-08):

# Animal-based model development

The implementation now follows the [model mathematics review](model-math-review.md). The supported statistical unit is an animal identified by a stable specimen ID. The biological reliability of the complete image workflow still requires independent data.

## Current behavior

- **Default method:** Procrustes/PCA/shrinkage-LDA when the selected inputs include complete, compatible landmarks; otherwise distance-kNN. The default reservoir setting is direct features. Cosine-kNN, the random-walk graph and optional random projections remain development comparators. A model's default method is fixed by this policy, rather than chosen from the highest cross-validation score. An explicit `primaryMethod` is available for controlled development experiments.
- **Reference representation:** exact repeated feature records within an animal are deduplicated. Non-landmark feature blocks are averaged across that animal's distinct views. Landmark views are Procrustes-aligned within the animal before computing its mean shape. Each resulting animal prototype contributes once to fitted GPA, scaling, PCA/LDA, covariance estimates, neighbor lists and graph topology. Prototypes use all selected blocks; views with missing required inputs are rejected rather than silently dropped.
- **Fitting order:** split whole animals into development folds and separate calibration groups first. Fit all learned transforms exclusively to the training animal prototypes. Queries and calibration wings use the frozen training transform. Nested LDA temperature fitting holds out training animals and refits alignment within each inner split.
- **Typicality:** the frozen model computes Euclidean distances in the unnormalized standardized feature space. A view's nonconformity is `1 + mean(distance to the nearest m same-taxon training animals)`, with default m = 3. One maximum view score per calibration animal enters the label-conditional split calibration. This retains feature magnitude even when the experimental similarity embedding discards it. Distance-kNN scores are relative similarity votes, not species probabilities.
- **Acquisition policy:** calibration uses all distinct recorded wing views of each animal; reference prototypes use their mean. A comparable single-wing query is conservative relative to the calibration maximum. Arbitrarily selecting or adding future views, changing acquisition conditions, or changing the number/type of calibration views does not establish exchangeability. Preserve a stated acquisition policy and verify coverage externally. The software cannot authenticate animal identities from IDs alone.
- **Development reporting:** each animal contributes one classification outcome, using the majority prediction across its distinct wings with a deterministic lexical taxon tie-break. Wing-level outcomes remain separately available in the exported report. Animal-level conformal sets are intersections of the view sets, matching maximum-view calibration. Balanced-accuracy intervals resample animals within each taxon; these are percentile bootstrap diagnostics conditional on the stored predictions, not full model-refitting uncertainty or an independent final test.
- **Degenerate inputs:** FlyHash rejects input dimensions at or below its fan-in; zero inputs produce empty tags. Noninformative feature sets and zero within-taxon variance produce actionable errors. LDA adds a small covariance floor proportional to training variance for otherwise singular covariance matrices.

The training input selector exposes complete-input, landmark-only, venation/outline and experimental paired venation/WIP contracts. Every reference must satisfy the chosen contract. WIP's biological identification value is not established by this repository.

## Model migration

The inference contract is `wingmate-model-3`, with an enforced animal-prototype policy, Euclidean calibration metric, one vector per training animal, and original-reference provenance. Existing v1/v2 models must be retrained. Current `wing-features-2` / `wing-normalizer-0.3` image references remain usable; this change does not require reprocessing their originals. Older image preprocessing still needs the previously documented reprocessing.

Training and calibration animals stay separate. Source hashes reused under different animal identities are rejected during training. The format stores all contributing training record IDs and the original reference provenance even though inference uses one animal prototype.

## Frozen external evaluation

An optional [three-species Bombus starter](../models/bombus-starter/README.md) is
bundled with the app. It is built from the pinned numeric Molasy & Tofilski
landmark database, not from source photographs. The unchanged CSV, adapted
reference database, publisher rights record, citation and ODbL notice accompany
the model. Export/import retains attribution; displayed predictions and external
test reports carry the same source notice. This is a development model with
insufficient cryptarum calibration and no independent final test. The other
European datasets discussed during research have not been downloaded or added.

Reserve an untouched test file of independently labelled animals before choosing features, parameters or models. Prefer separate acquisition sessions/collections. Keep whole unseen taxa out of training and calibration for the unknown-species test. Do not repeatedly tune on the resulting report.

Export a v3 model and a separate reference JSON file, then run:

```bash
node scripts/evaluate-model.mjs model.json independent-test-references.json report.json
```

The test file can be a reference-export object with a `references` array or a plain record array. Each record needs `id`, `specimenId` (or `group`), `species`, `features` and the matching `preprocessingVersion`; include acquisition `series` and source hashes where available. A novel taxon keeps its true expert label; do not relabel it as a supported species. All test records must satisfy the model's frozen input contract and feature version.

The evaluator never refits or recalibrates. It rejects detected overlap with training or calibration by animal ID, record ID, source-image hash or exact selected feature content. These checks inspect every original record before deduplication. It also rejects a test source image assigned to multiple animal IDs and missing true taxon labels. Identical features can also arise from distinct animals, so that conservative check requires a provenance review rather than changing IDs to bypass it. IDs and exact-source checks cannot prove the dataset was untouched during development.

The report includes SHA-256 fingerprints of both input files, supported-class animal recall/confusion, separate wing summaries, animal bootstrap intervals, known-class coverage/false rejection, and unknown-taxon rejection rates. Unknown-taxon rates are null if calibration is insufficient. LDA diagnostics include class-balanced Brier/mean-confidence values plus animal-level reliability bins and per-taxon confidence/accuracy; the latter use observed test prevalence and mean view posteriors. Shared acquisition-series IDs are reported for review. Report output cannot overwrite either input file.

## Current development benchmark

The regenerated landmark benchmark evaluates 814 wings from 423 animals, covering three Bombus taxa. It uses animal prototypes during fitting and animal outcomes during reporting:

| Method | Animal balanced accuracy |
| --- | --- |
| Procrustes + PCA + LDA | 89.65% |
| Random walk, direct features with cosine | 80.28% |
| Distance-kNN, direct standardized features | 78.47% |
| Cosine-kNN, direct features | 77.05% |

For LDA, the diagnostic balanced-accuracy interval is approximately 81.6–95.6%; recall is 85.7% for B. cryptarum, 88.7% for B. lucorum and 94.5% for B. terrestris. These animal-level results are not directly comparable to the old wing-level values. The method changes and statistical reporting unit both changed.

The benchmark still has zero animals with adequate calibration across every taxon, because B. cryptarum contains only 14 animals. The default 20% holdout needs at least 45 animals per taxon to obtain nine final calibration animals at epsilon 0.1. Nine only supplies the necessary p-value resolution. Neither synthetic outlier rejection nor the landmark benchmark demonstrates detection of actual unseen bee species.

Run `npm test` and `node scripts/audit-pipeline.mjs` for software checks. Regression cases cover radial outliers in all embedding modes, repeated-view invariance of fitting/calibration/graph and voting, animal-level evaluation, model export/import, legacy model rejection, source identity conflicts, degenerate numerical cases and frozen external-test overlap checks. Browser checks cover the training worker, input controls, model round trips, offline modules and updates.

## Apis reference collection

The pinned [Apis source](../models/apis-source/README.md) contains 29,043 wings
from 1,342 country-qualified colonies. Its adapted numeric collection preserves
original y-up coordinates and the separate Nawrocka (2018) landmark numbering,
with one reproducibly selected wing per colony and ODbL attribution. It is not
a feature export or an installable classifier. The UI offers a download that
also works offline. All unchanged numeric CSVs are included; photographs are
excluded. Two unmatched German filename joins are explicitly excluded.

Before combining it with Bombus, verify anatomical landmark homology, implement
and validate a common coordinate adapter, and freeze the new input contract.
Use colony-separated splits for Apis and country/acquisition holdouts; do not
interpret colony counts as independently sampled animal counts. Source-specific
acquisition may be confounded with species in a combined study. Neither this
collection nor internal cross-validation establishes transfer to app images.

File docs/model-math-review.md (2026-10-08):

# Model and mathematics review

Reviewed 2026-10-08 at commit `2b9741e`. Purpose: identification of bee species from venation images, optional paired WIP images, and manually placed landmarks. This review records the behavior before remediation. The subsequent changes and current protocol are documented in [model-development.md](model-development.md).

The numerical foundations are reasonable for a research prototype. The repository does not yet establish reliable species identification from new wing photographs, calibrated species probabilities under transfer, or reliable rejection of unseen species. The strongest current evidence supports the landmark classifier within the three tested Bombus taxa.

## Findings, ordered by consequence

### High: angular similarity can hide extreme feature outliers

[Embedding](../classifier/embedding.js) uses L2 normalization for the direct baseline and fixed-rank winner-take-all tags for FlyHash and dense projections. All three representations are invariant to positive rescaling of an already standardized feature vector. The conformal score uses similarity in that representation, so it cannot recover discarded magnitude.

A controlled probe trained on 45 independent animals per class, with two-dimensional shape features `[v, 0]`, using values from −2.44 to 2.89. Each class had nine separate calibration animals. A query at `v = 1972.31`, constructed by extending a known-class direction 1,000-fold from the fitted training mean, received best similarity 1 in every mode. Direct and dense modes returned the singleton set B with p-value 1; FlyHash returned both classes with p-values 1. Every mode reported `openSetValid: true` and `unknown: false`.

This is a synthetic counterexample, not a bee accuracy estimate. It exposes an architectural limitation of using angular similarity alone for unfamiliar-input detection. The conformal coverage theorem is not contradicted: it does not guarantee power against arbitrary outliers or unseen classes.

Recommendation: compare distances in the fitted, unnormalized feature space, including a regularized Mahalanobis or distance baseline where appropriate. Calibrate the resulting score with separate animals. Test unfamiliar species and acquisition failures explicitly; adding a distance threshold without recalibration would not preserve the existing coverage construction automatically.

### High: there is still no end-to-end or unknown-species validation

The stored [landmark benchmark](../test-data/landmark-benchmark.json) evaluates 814 wings from 423 animals, representing only three Bombus taxa. It contains `validQueries: 0`, `coverage: null`, and an empty `novelTaxon` result. The least represented taxon, B. cryptarum, has 14 animals; the default final 20% split supplies only two calibration animals. With that split policy, at least 45 animals per taxon are needed to obtain nine calibration animals in the final model. Nine is only the p-value resolution needed to reject at epsilon 0.1, not an adequacy or accuracy guarantee.

There is no independent final test after method selection, no complete image-to-identification accuracy benchmark, and no suitable real paired bee WIP/venation dataset in [the WIP notes](../test-data/wip/README.md). None of these gaps can be filled by checking matrix algebra or synthetic fixtures.

Recommendation: reserve independent animals and acquisition sessions before development; test the selected complete pipeline on them once. Evaluate unseen taxa separately. Measure modality ablations on the same paired animals before claiming WIP improves identification.

### Medium: animals define splits and calibration, but wings still define fitting and performance

[Model fitting and evaluation](../classifier/model.js) correctly keep an animal's wings together in each split. However, scaling, GPA, PCA/LDA and the reference graph still use individual wing records. [Metric summaries](../classifier/classify.js) also count wings. An animal with more records has more influence, and the effective independent sample size is smaller than the number of wings used by the PCA component heuristic and covariance fitting.

In a six-reference synthetic kNN probe, duplicating one B reference twelve times changed B's normalized score from 0.607 to 1, because duplicate records occupied all five nearest-neighbor slots. Class-count balancing did not eliminate this effect. The specimen-aware conformal neighborhood is protected against exact repetition; the ordinary kNN/graph stages are not.

Recommendation: specify the prediction unit and acquisition policy. Use equal-animal weighting or an explicit multi-view representation for fitting, select neighbors by animal, report animal-level performance, and bootstrap confidence intervals by animal rather than wing. Keep wing-level metrics as separately labelled descriptive results.

### Medium: degenerate inputs can create hashes or abort LDA fitting

[FlyHash projection](../classifier/embedding.js) samples `min(fanIn, inputDim)` distinct coordinates per cell. If input dimension is at most the default fan-in of six, every cell samples every coordinate, so their sums are mathematically identical. The output is determined by tie order or numerical rounding, rather than a useful projection. A zero vector nevertheless receives 13 active bits with 256 cells and 5% activity.

The default image descriptors have substantially more dimensions, so this is chiefly an edge case for small custom feature contracts such as size-only input. It must still be rejected or handled explicitly if that contract is supported.

[Automatic shrinkage LDA](../classifier/morphometrics.js) also fails on zero within-class covariance: shrinkage toward a scaled identity leaves an all-zero covariance all zero. Four identical two-dimensional rows with two labels produce “Kovarianzmatrix nicht positiv definit”.

Recommendation: reject noninformative and degenerate feature sets clearly, guard the sparse projection's low-dimensional case, and define a scale-aware covariance floor or a deliberate insufficient-data outcome for LDA.

### Medium: displayed confidence is not independently established

LDA implements equal class priors and shared covariance. Temperature fitting uses grouped inner held-out predictions with class-balanced log loss; this is a reasonable development procedure, but the resulting probabilities refer to that balanced population and known classes. Actual field prevalence may differ. A close mean confidence and mean accuracy does not establish reliability at every confidence level or for each taxon.

The stored benchmark's mean top probability is 88.2%, versus 86.8% balanced accuracy, with Brier score 0.161. Those are development diagnostics, not prospective probability calibration. The graph's normalized, class-count-balanced scores are relative similarity scores rather than posterior species probabilities. An empty conformal set can indicate poor acquisition or missing reference diversity as well as an unfamiliar species.

Recommendation: validate reliability curves, per-taxon calibration, proper scores and selective error rates on independent animals. Tune any deployment priors within a stated protocol. Define the same view-selection/aggregation policy for calibration and future queries; animal-max calibration is conservative for a comparable single view but does not justify arbitrary future view selection or acquisition changes.

## What is mathematically sound

The reviewed generalized Procrustes rotation, centering and centroid-size normalization have the expected form and preserve reflection as a separate anatomical decision. PCA and the LDA discriminants implement the usual linear algebra. LDA uses a pooled within-class covariance and shrinkage toward a scaled identity; its equal-prior coefficients are `w_k = Sigma^-1 mu_k` and `b_k = -0.5 mu_k^T w_k`. This agrees with the [standard LDA formulation](https://scikit-learn.org/stable/modules/lda_qda.html).

Independent NumPy checks on controlled matrices gave:

| Check | Observed discrepancy |
| --- | --- |
| 38-dimensional symmetric eigenvalues versus NumPy `eigh` | Maximum absolute error 6.93e-14 |
| Eigenvector equation, relative matrix residual | 5.33e-15 |
| Eigenvector orthogonality | Maximum error 7.33e-15 |
| LDA coefficients versus an independently constructed pooled/shrunk covariance solve, fixed shrinkage 0.2 | Maximum error 1.14e-7, consistent with stored Float32 coefficients |
| Random-walk transition row sums | Maximum error 2.22e-16 |
| 40-step reference scores versus a direct stationary-system solve | L1 difference 2.42e-7 on the probe |

The random walk is `p_next = alpha e_query + (1-alpha) P^T p`. At the default alpha 0.2 it is mass-preserving and contractive for the valid stochastic rows. The worst-case node-distribution L1 bound after 40 steps is `2 * 0.8^40 = 0.000265846`. This bound concerns numerical convergence, not identification accuracy. Changing alpha requires revisiting the iteration budget.

The frozen split-calibration p-value `(1 + number of calibration scores >= query score) / (n + 1)` has the standard finite-sample form, with one maximum score per calibration animal and disjoint training animals. Its statistical interpretation still requires a fixed scoring protocol and comparable independent animals. Known-class set coverage does not imply unknown-species detection power. See [Angelopoulos and Bates](https://arxiv.org/abs/2107.07511), particularly class-conditional prediction and outlier detection.

Temperature scaling is an established calibration approach, but transfer of its empirical performance to this application must be measured: [Guo et al.](https://proceedings.mlr.press/v70/guo17a.html).

## Evidence for choosing a method

These are stored development results, evaluated on held-out animal groups but summarized over wings. The benchmark was inspected rather than regenerated in this review.

| Method | Balanced accuracy |
| --- | --- |
| Procrustes + PCA + LDA | 86.85% |
| kNN, direct standardized coordinates with cosine | 80.05% |
| Random walk, direct coordinates with cosine | 79.07% |
| Random walk, FlyHash 2,048 cells | 79.20% |
| Random walk, FlyHash 4,096 cells | 79.68% |

LDA's overall accuracy is 94.84%, but its B. cryptarum recall is 75%; the abundant B. terrestris records make overall accuracy look substantially stronger than balanced accuracy. No uncertainty intervals are supplied, and this comparison does not establish a statistically significant method advantage or performance on other genera.

My assessment is to retain Procrustes/PCA/shrinkage-LDA as the primary development baseline for the anatomically compatible Bombus landmark workflow. Keep kNN and the graph as comparators until an independent study shows value. The stored results do not demonstrate that FlyHash or the graph adds a material identification benefit, and FlyHash is a fixed random embedding rather than a learned image encoder.

Wing-image identification itself is plausible: [Spiesman et al.](https://journals.plos.org/plosone/article?id=10.1371/journal.pone.0303383) studied a CNN on 1,069 wing images covering 18 species from four genera. That supports testing learned image features, but validates neither this implementation nor its WIP fusion.

The existing pipeline audit probes were rerun, along with the Node test suite. Numerical agreement and software tests support implementation correctness on their covered cases; the application needs the independent biological evaluation above before reliable deployment claims are warranted.

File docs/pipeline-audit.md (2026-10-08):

# Bee wing identification: pipeline audit

Reviewed 2026-10-07 against base commit `d43485e` and the current working tree. Scope: image processing, feature extraction, training, validation, identification and result interpretation. Physical capture hardware is outside scope. This review adds diagnostics and documentation; it does not change the classifier or imaging behaviour.

The app is a useful research prototype. Its current evaluation and calibration do not establish reliable identification of new bee specimens. The first blockers are leakage between training and validation, calibration that counts wing records instead of independent animals, and insufficient evidence for combined venation/WIP identification. The random-walk recurrence itself is consistent with its intended definition at the default settings.

## First remediation pass

The findings below record the pre-fix review. The current implementation now:

- Refits alignment, scaling, PCA/LDA and nested landmark temperature calibration inside training groups, including collection holdouts. The live validation path uses the same grouped evaluator.
- Reserves separate calibration animals per taxon, using one maximum wing nonconformity score per animal. Repeated records do not create independent calibration samples. Query typicality uses the same frozen training representation and animal-aware neighbours. Live jackknife is explicitly heuristic and cannot enable calibrated unknown decisions.
- Requires stable animal IDs when adding references and when evaluating/training; detects conflicting labels and exact-image reuse under another identity.
- Requires an explicit input contract when diagnostic modalities are incomplete; venation-only and paired venation/WIP modes are available.
- Measures image detail in an eroded interior and excludes the interpolation halo from colour/vein descriptors. Uniform silhouettes have zero vein features and are marked for review. Review overrides require a stored reason, and paired images require same-wing/internal-correspondence confirmation.
- Uses model format `wingmate-model-2`, complete reservoir/classifier parameters, enforced feature/preprocessing contracts and content fingerprints. Old models require retraining; old image references need reprocessing from archived originals.
- Replaces the globally fitted landmark benchmark with five-fold grouped development evaluation, including training-group-only alignment and nested temperature fitting.

The calibration aggregation is conservative for a single-wing query: the calibration score is the maximum across that animal's available wings. Coverage still requires comparable animals and a consistent view-acquisition policy; adding arbitrary numbers or types of views is not a general exchangeability guarantee. Independent final testing, held-out-species evaluation, expert-labelled real paired WIP data and an actual learned image encoder remain future work. Development method selection is labelled as such in the UI.

Run `node scripts/audit-pipeline.mjs` to inspect current behaviour. Its output now shows corrected/rejected cases rather than reproducing the old failures.

## Follow-up verification (2026-10-08)

The read-only audit probes and Node suite pass against the remediation implementation. The probes show identical animal counts and p-values after wing duplication, matching fold-only fitting results, explicit rejection of incomplete modalities and feature-version mismatches, enforcement of saved classifier settings, and zero vein features for the uniform silhouette.

The remaining interface findings are addressed in [the UI remediation record](img/uifix.md). The user manual now distinguishes live heuristic typicality from frozen-model split calibration and counts independent calibration animals rather than reference wings.

Independent final testing, unseen-taxon testing, real paired WIP evidence, anatomical correspondence validation and learned image features remain research work. The local fixtures cannot supply those missing observations.

## Second remediation pass (2026-10-08)

The code now fits one distinct-view prototype per animal, uses unnormalized standardized-feature distances for calibration, and defaults to landmark LDA or distance-kNN. Evaluation reports animal outcomes and bootstrap diagnostics; the graph and FlyHash remain comparators. Model format v3 requires retraining. A frozen external evaluator rejects detected training/calibration reuse and separates known-class errors from unseen-taxon rejection. See [the current development protocol](model-development.md) for acquisition assumptions, migration and reproduction. The descriptive pipeline below records the earlier implementation; the linked protocol describes the current defaults.

## What the software did at the first review

```mermaid
flowchart TD
    A[Venation image and/or WIP image] --> B[Segment wing and confirm orientation]
    B --> C[Normalize to 1024 x 512]
    C --> D[Downsample to 256 x 128]
    D --> E[Handcrafted shape, gradient and colour features]
    E --> F[Reference-fitted scaling and fixed FlyHash projection]
    F --> G[Similarity graph and random walk with restart]
    G --> H[Relative taxon scores]
    F --> I[Nearest-neighbour vote and separate typicality calculation]
    B --> J[Optional manual landmarks]
    J --> K[Procrustes alignment, PCA and LDA]
    K --> L[Alternative taxon prediction]
```

| Stage | Implementation | Meaning for bee identification |
| --- | --- | --- |
| Image preparation | Segment at up to 640 pixels on the longest axis, estimate orientation, preserve transforms, normalize original RGB to 1024 × 512. Optional software flat-field correction. | Useful deterministic foundation; mask and orientation still need anatomical review. |
| Pair alignment | Bounded rotation, uniform scaling and translation optimize silhouette overlap. | Aligns contours; does not verify vein correspondence or that both images show the same wing. |
| Features | Shape: 66 values. Venation: 288 gradient/darkness values. WIP: 112 Lab/hue/chroma values. Optional metric size and landmarks. | Coarse descriptors, not an explicit detector of vein junctions or wing-cell topology. |
| “Neural” representation | Fixed seeded sparse random projection, normally 2,048 outputs with 5% active. Optional dense projection or exploratory connectome diffusion. | No supervised image encoder is trained. The connectome mode is explicitly excluded from frozen-model training. |
| Training | Fits feature scaling and landmark alignment; fits PCA/LDA and temperature where available; compares methods and stores reference vectors. | This is statistical model fitting and reference preparation. It does not learn image features through backpropagation. |
| Markov classifier | Directed similarity kNN graph, query restart, class-balanced reference mass. | Propagates similarity evidence. It cannot recover anatomical information absent from the features. |

Sources in code: [pipeline](../imaging/pipeline.js), [registration](../imaging/registration.js), [features](../classifier/features.js), [embedding](../classifier/embedding.js), [training](../classifier/model.js), [classification](../classifier/classify.js).

FlyHash is a biologically inspired similarity-search construction. Its original research does not establish bee-wing identification accuracy. [Dasgupta, Stevens and Navlakha, 2017](https://pubmed.ncbi.nlm.nih.gov/29123069/).

## Findings, in priority order

### 1. High: held-out specimens influence the fitted representation

In `classifier/model.js:130`, generalized Procrustes alignment and the standardizer are fitted to all references before folds are constructed at line 142. Excluding nodes from the classifier graph does not remove their contribution to that fitted representation. Series holdouts reuse it too. PCA/LDA are refitted within folds, but their input landmark alignment was already fitted globally.

The live validation path (`app.js:467`) and landmark benchmark (`scripts/landmark-benchmark.js:46` and `:95`) have the same ordering problem. Live landmark inference also aligns references and the query together, whereas a frozen model uses a stored reference mean.

**Reproduction:** on a controlled 30-record synthetic dataset, the existing five-fold RWR result is **63.3%** balanced accuracy. Refitting only the standardizer within the identical folds gives **56.7%**. kNN changes from **50.0%** to **46.7%**. These numbers demonstrate a consequential implementation difference; they are not bee accuracy estimates or a general estimate of the bias.

**Required change:** split animals first; fit every data-dependent transformation on training specimens only; align/transform held-out specimens using the fixed training transformation. Keep method selection and calibration inside the development process, with a sealed external test or an outer evaluation loop. Regenerate the published benchmark results afterward. Fitting label-free preprocessing on validation data is still leakage for this frozen-model evaluation. [Official scikit-learn guidance](https://scikit-learn.org/stable/common_pitfalls.html#data-leakage).

### 2. High: repeated wings can falsely establish calibration validity

`classifier/classify.js:146` correctly excludes the whole animal when computing each calibration score. However, it returns one score per wing. `conformalPredict` at line 153 then pools these scores and determines sufficiency from the number of wing records, without specimen groups. The UI calls these records “Referenzexemplare” and displays an approximately 90% coverage statement (`app.js:445`).

**Reproduction:** five independent animals per species, with one wing each, yield `openSetValid: false` and p-values of **1/6** for a deliberately dissimilar query. Duplicating each wing under the same animal ID gives ten records per species, `openSetValid: true`, p-values of **1/11**, and an “unknown” decision. No independent animals were added.

There is a second protocol issue: leave-group-out calibration scores are compared with a query scored against the complete reference set. This is not automatically a valid split-conformal or full-conformal construction. The known-class evaluation also reuses calibration scores whose construction included the evaluated animal among other animals' neighbours. Global preprocessing adds the leakage described above.

**Required change:** define the prediction unit as an animal, choose a consistent aggregation policy for repeated views/wings, and use disjoint training, calibration and test animals with the same fixed scoring function for calibration and future queries. A different grouped conformal construction needs its own justified protocol. Counting nine records only establishes p-value resolution; it does not establish coverage. Known-class prediction-set coverage and detection of previously unseen species must be evaluated separately. Conformal guarantees depend on the construction and its exchangeability assumptions. [Angelopoulos and Bates, conformal prediction tutorial](https://arxiv.org/abs/2107.07511).

### 3. High for evaluation: specimen identity is optional

`app.js:86` falls back from an optional specimen ID to an archive ID and then a reference ID. `addReference` at line 132 rejects reuse of the same archive, but accepting the same animal again can create a new archive. Thus grouped folds only protect against repeated animals when the supplied identity is stable. Live identification excludes the current archive, not every record of the same animal.

**Required change:** require a stable animal ID for reference/calibration/evaluation records; separately record wing ID, side, modality and acquisition session. Flag exact-file duplicates using the available source hashes, without treating hash uniqueness as proof of distinct animals. Resolve conflicting labels within an animal. Keep all views and augmentations of one animal in one split. Report animal counts alongside wing counts.

### 4. Medium: one missing modality removes it from the whole model

`classifier/embedding.js:20` computes the intersection of feature blocks across every record. Training uses that intersection at `classifier/model.js:126`. Live comparison also includes the query in this selection.

**Reproduction:** 30 references, all with shape and venation and 29 with WIP, train a model with only `shape` and `venation`. WIP is dropped for all 29 paired references. Mixed venation-only and WIP-only records can reduce the comparison to shape alone. Missing landmarks similarly remove the landmark method from the shared training path.

**Required change:** make model inputs explicit before training. Start with separate venation-only and paired venation/WIP models and a clear eligibility check. Missing-modality-aware fusion is another option, but needs its own training and evaluation. Display the active input mode and sample coverage; do not imply a paired model was trained when WIP was discarded. Compare modalities on identical animal splits.

### 5. Medium: “GOOD” geometry does not establish usable anatomical signal

`imaging/pipeline.js:88` measures sharpness and clipping, but does not apply a validated sharpness or vein-detail requirement. The Laplacian calculation in `imaging/rig.js:251` includes the silhouette boundary and neighbours outside the mask. `imaging/qc-ui.js:444` enables acceptance after processing and orientation confirmation even when QC or pair registration needs review.

**Reproduction:** the existing uniform-gray silhouette fixture contains no veins. It nevertheless receives mask status **GOOD**, no reasons for review and sharpness **1558.05**. Its normalized image produces venation descriptor norm **9.9143**, including nonzero gradient and darkness components. Replacing all normalized pixels inside that same mask with the original constant gray makes both components exactly zero. This isolates contamination introduced during image normalization around the boundary; the current feature masking does not fully eliminate its effect.

Registration is explicitly contour-only (`imaging/registration.js:99`). An identical mask gets IoU 1 regardless of internal anatomy or colour because RGB and landmarks are not inputs to that function. This is an implementation limit, not evidence that registration can authenticate an image pair.

**Required change:** distinguish mask geometry, anatomical detail, WIP signal and pair alignment in software QC. Measure internal detail away from the contour; reject or explicitly review insufficient information and clipping. Avoid amplifying nearly uniform interiors into apparent vein features. Use explicit reviewed eligibility for training, with recorded reasons for overrides. Bind image pairs to the same animal and wing before fusion. Validate internal correspondence on annotated real pairs. The WIP block currently samples the whole wing mask, including veins; it has no separate membrane/vein mask.

### 6. Medium: frozen-model metadata is not fully enforced

`classifier/model.js:252` checks the model-container version, but query classification does not enforce the saved feature/preprocessing versions. `missingBlocks` checks presence and landmark compatibility; the standardizer checks dimensions, but finite values are not validated. Saved classifier settings are written at line 216 and ignored by the inference calls at lines 284–286, which use current defaults. Reservoir settings store overrides rather than all resolved defaults.

**Reproduction:** a query with an incompatible feature-version string is accepted by `loadModel(...).classify(...)`. Setting the saved restart probability to 1 still returns ordinary taxon scores; directly passing that setting to `rwrScores` produces no reference mass, as expected at that boundary value.

**Required change:** store and enforce a complete model contract: resolved parameters, preprocessing and feature versions, dimensions, finite-value checks, landmark scheme, taxonomy and reference provenance. Reject incompatible queries with a clear message. Reloading the same artifact must reproduce the same outputs. The reference fingerprint also needs feature/label content, not only reference IDs, if it is to detect changed training data.

## Markov-chain assessment

At the defaults, `rwrTransitions` builds normalized outgoing rows with `k = 7` and weights `max(0, cosine)^3 + 1e-12`. The query is an additional node. `rwrScores` implements, for a column probability vector:

`p_next = 0.2 * e_query + 0.8 * transpose(P) * p`

The recurrence conserves mass for valid input, and the query restart makes it contractive. In exact arithmetic, the worst-case L1 distance from the stationary distribution after 40 iterations is bounded by `2 * 0.8^40`, approximately `0.000266`. This bound concerns node probabilities, not classification error or calibrated taxon probabilities. The visualization shares these transition rows with scoring.

Taxon scores sum reference mass, divide by each taxon's reference count when balancing is enabled, then renormalize. They are **relative class-balanced similarity scores**, not posterior probabilities or a temporal model of bee behaviour. The walk itself does not learn image features. Also, balancing label counts does not remove the effect of duplicate records on the graph's topology.

The tiny positive edge floor means even uniformly poor similarities can produce normalized scores. Keep a separately validated abstention mechanism. Tune graph parameters only within development folds, and retain the graph stage if it adds measurable value against simpler classifiers on the same held-out animals. It is reasonable to keep it as an interpretable experimental method while those comparisons are made.

## Evidence for venation and WIP

The repository's [image dataset notes](../test-data/README.md) describe 36 development images/panels, including publication crops, not an independent deployment test. The stored image benchmark records 34 REVIEW and 2 GOOD results; those are QC outcomes, not segmentation accuracy, because curated reference masks are absent. The larger landmark benchmark covers 814 wings from 423 specimens and explicitly evaluates the classification stage, not the complete image pipeline. Its global fitting must be corrected before using its accuracy as prospective performance evidence.

The [WIP dataset notes](../test-data/wip/README.md) explicitly state that the repository lacks suitable real paired bee venation/WIP images from that search. Synthetic colour fixtures establish geometry and colour-value preservation only. Consequently, this repository does not yet establish the additional identification value of WIP.

Bee-wing image classification is a plausible direction: Spiesman and colleagues trained a CNN on 1,069 wing images covering 18 species from four genera. That is evidence within their studied taxa and data; it is not validation of this app or of paired WIP fusion. [Spiesman et al., 2024](https://journals.plos.org/plosone/article?id=10.1371/journal.pone.0303383).

WIPs have a biological basis as structural colour patterns. The foundational study describes stable patterns in small wasps and flies, including stability over broad illumination angles; treating WIP as inherently random colour would be misleading. Its usefulness for the selected bee taxa and this software must be measured with real images. Lab conversion alone does not establish calibrated colour. [Shevtsova et al., 2011](https://www.neotropicaleulophidae.com/pdfs/WIP.pdf).

Only the `bombus-19` landmark scheme is currently implemented. Its anatomical correspondence cannot simply be assumed across all bee genera; the scheme itself notes that other venation arrangements require other schemes.

## Recommended process for this scope

1. **Define the identification target.** Specify the supported species/region and whether the product reports species, a species group or unresolved candidates. Obtain expert-confirmed labels and enough independent animals to estimate per-species errors. The existing ten-animal readiness threshold is a heuristic, not a demonstration of statistical adequacy.
2. **Establish the dataset contract.** Store animal/wing identity, side, paired modalities, session/source, label provenance and software-QC eligibility. Partition animals before data-dependent fitting or augmentation. Reserve independent sessions/collections for transfer testing and whole unseen taxa for unknown-species evaluation.
3. **Repair validation and uncertainty first.** Fit transformations within folds, separate calibration animals, correct repeated-wing counting and evaluate the final selected method on untouched data. Report per-species recall/confusion, balanced accuracy, animal counts, uncertainty intervals, false rejection of known species and detection of unknown species separately.
4. **Compare venation, WIP and their combination.** Use the same held-out animals with paired data for a fair comparison. Include shape-only, handcrafted features without FlyHash, landmarks/PCA/LDA where anatomically applicable, nearest-neighbour and Markov baselines. Include sensitivity to missing modalities and reviewed poor-quality images.
5. **Add learned image features as a measured experiment.** If the goal includes neural image training, train an actual image encoder offline, initially using a pretrained vision model. Compare a venation branch with separate venation/WIP branches and validated fusion. Geometric augmentation must preserve anatomical orientation conventions; colour augmentation must be tested so it does not destroy WIP signal. Choose image resolution by measured preservation of diagnostic details. A neural model is a candidate, not a guaranteed improvement over landmarks or simpler features.
6. **Export one reproducible inference artifact.** Freeze preprocessing, encoder/scaler, reference representation, classifier, calibration protocol and supported inputs together. Show the user the candidate taxon/set, relevant reference wings, input mode and a concise reason when the system cannot decide. Keep graph mechanics in the explanatory view.

## Verification and reproduction

The existing `npm test` suite passed all seven test files during this review. This verifies the covered software behaviour, not biological identification accuracy.

Run the additional read-only probes with:

```bash
node scripts/audit-pipeline.mjs
```

The JSON output checks calibration duplication, fold-only fitting, explicit missing-modality handling, model contracts, uniform-silhouette descriptors and contour-only registration against the current implementation. These are diagnostic observations rather than regression assertions. They deliberately use synthetic inputs to isolate mechanisms; they do not provide accuracy estimates on bees. No training-data downloads or hardware changes are needed to run them.

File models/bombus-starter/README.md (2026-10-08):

# Three-species Bombus starter

This optional frozen model identifies candidates among **B. cryptarum,
B. lucorum and B. terrestris** using 19 manually placed `bombus-19` landmarks.
Load it under **Referenzen → Modell trainieren → Bombus-Startmodell laden**.
No personal reference images are replaced or added. Selecting **Kein Modell**
returns to the local live comparison. Exported model JSON retains the citation,
source checksums, licence notice, adaptations and limitations.

The package uses 814 published wings from 423 animals (14 cryptarum, 62 lucorum,
347 terrestris). Both wings stay in one animal during splitting and evaluation.
Source landmarks are converted from y-up into the same base-left/anterior-up
handedness as the UI. Translation and uniform image scale are removed by
Procrustes; no source image normalization is asserted. The feature/preprocessing
version tags declare compatibility with current UI landmark coordinates.

It is a **development model**, not a general European bee classifier. It has no
independent final test, automatic landmark detector, paired WIP training, or
validation of the full image workflow. In particular, cryptarum provides only
two final calibration animals, below the nine required at epsilon 0.1. Therefore
the package cannot establish reliable exclusion of unknown bee species. A high
LDA posterior is conditional on the supported taxa and is not proof that the
animal belongs to them. Do not change epsilon merely to hide the data shortage.

Collection/session metadata were not verified and are left unknown. Future
external tests must contain new, independently labelled animals from separate
acquisition sessions, with matching landmark definitions and anatomical review.
The published source is already development data, including records used in
the repository's benchmark and browser fixtures.

Rebuild locally, without downloads:

```bash
npm run build:starter
```

The build verifies the archived publisher licence declaration and source MD5,
then fits all folds and the final model from the numeric data. Source SHA-256
checksums and the exact build recipe are embedded in the exported artifact.
`references.json` is the numeric build/evaluation database, not a QC-approved
image-reference import. `source-landmarks.csv` is the unchanged original CSV.

Read [NOTICE.md](NOTICE.md) for citation, adaptations and ODbL 1.0 terms. The
numeric model/reference database is distributed separately from the application
code. See [the development protocol](../../docs/model-development.md) for fitting
and evaluation assumptions.

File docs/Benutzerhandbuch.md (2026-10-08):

# Wingmate – Benutzerhandbuch

Wingmate bestimmt Wildbienen anhand ihres Vorderflügels: der **Aderung** (Venation, im Durchlicht)
und optional der **Wing Interference Patterns** (WIP, Schillerfarben im Auflicht auf schwarzem
Grund). Die App läuft vollständig im Browser, auch am Smartphone und offline. Bilder, Referenzen und
Modelle verlassen das Gerät nicht.

> **Forschungsprototyp.** Wingmate ersetzt keine taxonomische Bestimmung. Jedes Ergebnis ist ein
> Hinweis mit Unsicherheit; die Qualität hängt direkt von Ihren Referenzen ab (Kapitel 10).

**Inhalt**

1. [Starten](#1-starten)
2. [Die Oberfläche in 1 Minute](#2-die-oberfläche-in-1-minute)
3. [Aufnahme-Rig einrichten und kalibrieren](#3-aufnahme-rig-einrichten-und-kalibrieren)
4. [Ein Exemplar aufnehmen](#4-ein-exemplar-aufnehmen)
5. [Prüfen: Maske und Orientierung](#5-prüfen-maske-und-orientierung)
6. [Landmarken setzen](#6-landmarken-setzen)
7. [Freigeben – und dann: Referenz oder Bestimmung](#7-freigeben--und-dann-referenz-oder-bestimmung)
8. [Das Ergebnis lesen](#8-das-ergebnis-lesen)
9. [Modell trainieren](#9-modell-trainieren)
10. [Gute Referenzen sammeln](#10-gute-referenzen-sammeln)
11. [Daten sichern](#11-daten-sichern)
12. [Einstellungen](#12-einstellungen)
13. [Fehlerbehebung](#13-fehlerbehebung)
14. [Begriffe](#14-begriffe)

---

## 1. Starten

**Am einfachsten:** <https://hofda.github.io/wingmate/> im Browser öffnen – am Computer oder am
Smartphone. Die Adresse ist verschlüsselt (HTTPS), deshalb funktioniert auch die Kamera.

**Als App installieren** (empfohlen fürs Smartphone, danach auch offline nutzbar):

- **Android / Chrome, Desktop:** Browsermenü → *App installieren* (oder *Einstellungen → App →
  App installieren*, sobald der Browser es anbietet).
- **iPhone / iPad (Safari):** *Teilen → Zum Home-Bildschirm*.

Oben rechts steht **Offline bereit**, sobald die App einmal vollständig geladen wurde.
Erscheint **Update laden**, gibt es eine neue Version: vorher laufende Arbeit freigeben oder
exportieren, dann klicken.

**Lokal aus dem Quellcode** (für Entwicklung):

```bash
npm run serve          # Computer: http://localhost:8000
npm run serve:https    # Smartphone im selben WLAN: https://<IP-des-Rechners>:8443
```

Beim HTTPS-Server einmal die Zertifikatswarnung auf dem Smartphone bestätigen.

**Welcher Browser?** Für Aufnahmen mit fixierter Kamera: **Chrome auf Android**. iPhone-Safari
funktioniert, erlaubt Webseiten aber keine manuelle Kamerasteuerung (Kapitel 4).

---

## 2. Die Oberfläche in 1 Minute

Wingmate hat vier Bereiche – am Computer oben, am Smartphone unten:

| Bereich | Wofür |
| --- | --- |
| **Exemplar** | Bild laden oder aufnehmen, prüfen, Landmarken setzen |
| **Ergebnis** | Bestimmung des aktuellen Exemplars |
| **Referenzen** | Ihre sicher bestimmten Exemplare (= Trainingsdaten) und das Modelltraining |
| **Einstellungen** | Aufnahme-Rig, Rechenraum, App, Methodik |

Im Bereich *Exemplar* zeigt die **Leiste am unteren Rand** immer, wo Sie stehen
(**Bild · Geprüft · Landmarken x/19**) und den **nächsten Schritt**. Wenn Sie nicht wissen, was als
Nächstes zu tun ist: auf die Leiste schauen.

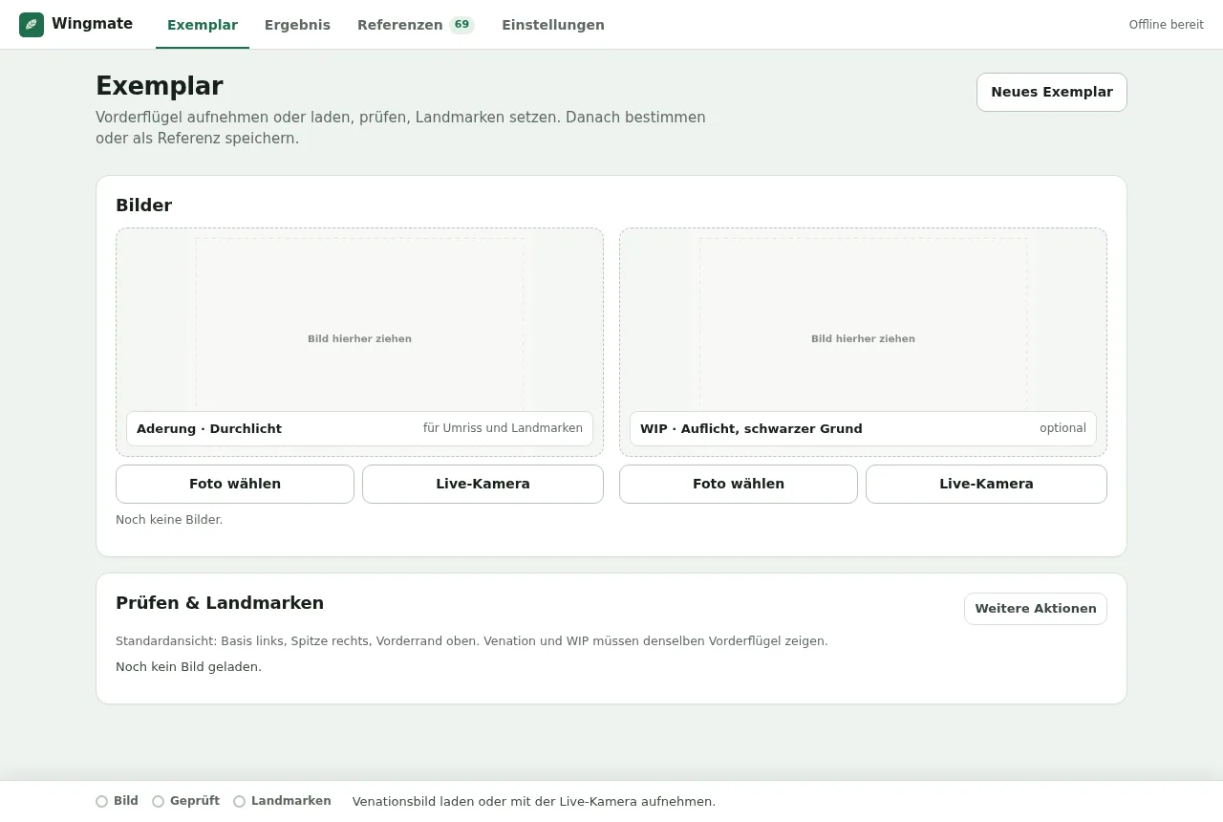
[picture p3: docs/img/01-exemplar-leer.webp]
Exemplar-Bereich am Computer, noch leer


Der ganze Ablauf für ein Tier:

1. **Bild** laden oder aufnehmen (Kapitel 4)
2. **Prüfen**: Maske und Orientierung bestätigen (Kapitel 5)
3. **Landmarken** setzen (Kapitel 6, für die zuverlässigste Bestimmung)
4. **Freigeben**, dann **Bestimmen** oder **Als Referenz** speichern (Kapitel 7)

---

## 3. Aufnahme-Rig einrichten und kalibrieren

Ein **Rig** ist Ihr fester Smartphone-Aufsatz: immer gleicher Abstand, gleicher Hintergrund, gleiches
Licht. Wingmate kann ein Rig einmal **kalibrieren** und korrigiert danach jede Aufnahme automatisch:
ungleichmäßiges Licht und Farbstich werden ausgeglichen, Staub auf Glas oder Diffusor stört die
Flügelerkennung nicht mehr, Abweichungen (Rig verrutscht, Licht geändert) werden gemeldet, und mit
einem Maßstab misst die App die **Flügellänge in mm**.

Ohne Rig funktioniert die App auch – dann ohne diese Korrekturen und ohne mm-Größe.

### Hinweise für den Bau

Ein fertiges, 3D-druckbares Rig für iPhone-Makro mit LED-Leuchtkasten liegt in
[`rig/`](../rig/README.md) (STL, Teileliste, Montage, Kalibrierung).

- Flügel **flach zwischen Objektträger und Deckglas** (ein Tropfen 70 % Ethanol hilft beim Glätten),
  in einem festen Schlitz auf der Fokusebene.
- **Venation:** gleichmäßiges, diffuses Durchlicht (LED-Panel mit Opal-Diffusor). LEDs mit
  **Konstantstrom, ohne PWM-Dimmung** – PWM erzeugt Streifen im Bild, die sich nicht herausrechnen lassen.
- **WIP:** lichtschluckender schwarzer Untergrund (Velours/Flock), Auflicht unter **festem Winkel**.
  WIP-Farben ändern sich mit Licht- und Blickwinkel.
- Gehäuse geschlossen halten (kein Umgebungslicht), Lampen mit hoher Farbwiedergabe (CRI ≥ 90).
- Makro-Vorsatz fest auf der **Hauptkamera**; manche iPhones wechseln im Nahbereich sonst
  selbstständig das Objektiv.

### Kalibrieren

1. Rig montieren, Licht an.
2. *Einstellungen → Aufnahme-Rig → **Mit der Live-Kamera kalibrieren*** (oder im Bereich *Exemplar*
   bei einem Bildfeld **Live-Kamera** und dort **Rig kalibrieren** aufklappen).
3. Kamera einpendeln lassen, dann unter *Kameraeinstellungen* **Aktuelle Einstellungen fixieren**
   (nur Android-Chrome).
4. Die Kalibrierschritte nacheinander **Aufnehmen** – jeweils ohne Flügel:
   - **Venation-Hintergrund:** leerer Objektträger im Durchlicht *(nötig für Venation)*
   - **WIP-Hintergrund:** leer, schwarzer Grund, Auflicht *(nötig für WIP)*
   - **WIP-Graukarte:** neutrale Graukarte an der Flügelposition *(optional, verbessert WIP-Farben)*
   - **Maßstab:** Lineal oder Objektmikrometer an der Flügelposition; im Bild **zwei Punkte
     anklicken** und ihren Abstand in mm eintragen *(optional, für mm-Größe)*
5. Namen eingeben, **Rig speichern & aktivieren**.

Jede Hintergrundaufnahme mittelt 16 Bilder. Das Profil gilt **nur für genau diese Auflösung,
Zoomstufe und Beleuchtung**. Nach einem Wechsel von Lampe, Diffusor, Vorsatzlinse oder Telefon neu
kalibrieren. Unter *Einstellungen → Aufnahme-Rig* können Sie Rigs wählen, **exportieren** (z. B.
für ein zweites Gerät), **importieren** und löschen.

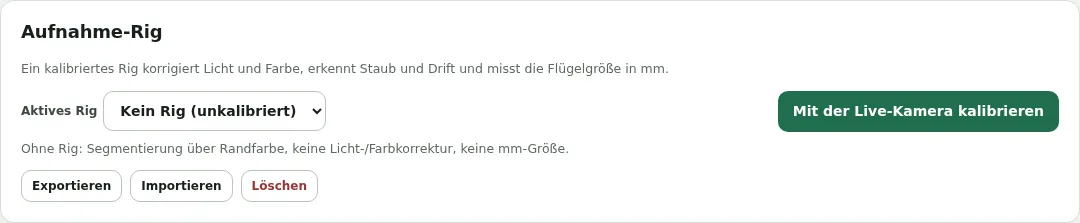
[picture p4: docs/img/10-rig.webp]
Aufnahme-Rig in den Einstellungen


---

## 4. Ein Exemplar aufnehmen

Im Bereich **Exemplar → Bilder** gibt es zwei Felder:

- **Aderung · Durchlicht** – das Hauptbild; nötig für Landmarken
- **WIP · Auflicht, schwarzer Grund** – optional

Zu jedem Feld gibt es zwei Wege:

**Foto wählen** öffnet eine Bilddatei. Am Smartphone bietet der Browser dabei auch die
**Kamera-App** an (volle Auflösung; in der Kamera-App Fokus/Belichtung per langem Tippen sperren).
Am Computer können Sie ein Bild auch ins Feld **ziehen**.

**Live-Kamera** nimmt direkt in Wingmate auf:

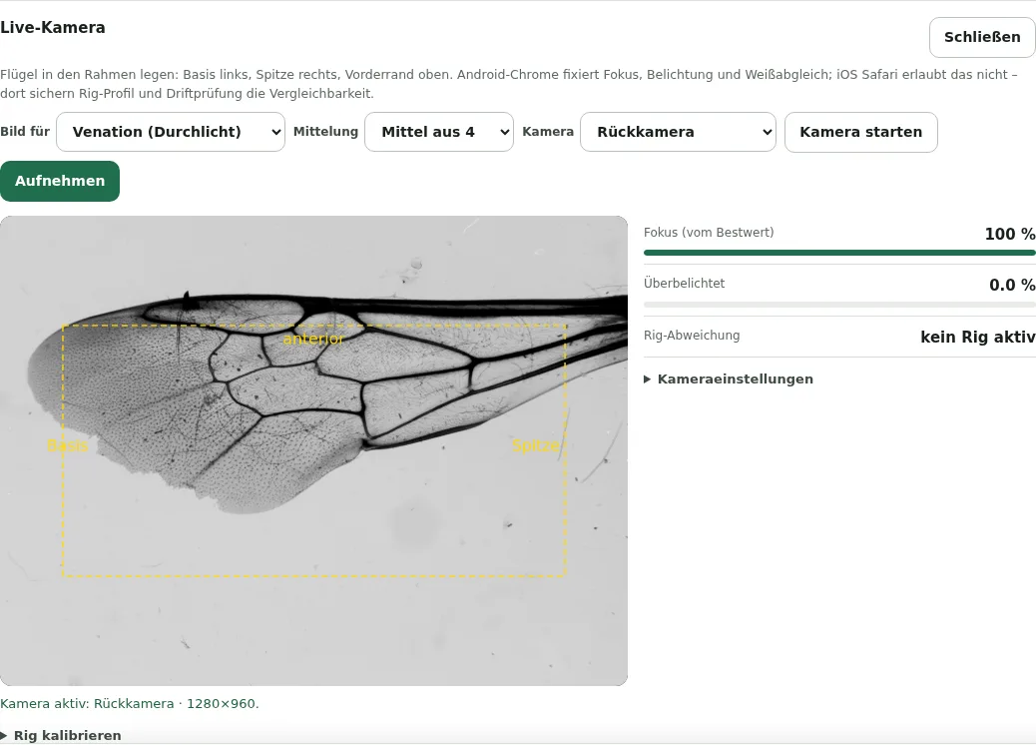
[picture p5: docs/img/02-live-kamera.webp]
Live-Kamera mit Platzierungsrahmen und Anzeigen


1. Den Flügel in den **gelben Rahmen** legen: **Basis links, Spitze rechts, Vorderrand oben**.
2. Auf die Anzeigen rechts achten:
   - **Fokus (vom Bestwert):** möglichst nahe 100 %. Der Wert ist relativ zum schärfsten Bild dieser Sitzung.
   - **Überbelichtet:** sollte 0 % sein. Überbelichtete Stellen im Flügel sind verlorene Information.
   - **Rig-Abweichung:** mit aktivem Rig; ⚠ bedeutet, dass Licht oder Position vom Profil abweichen.
3. **Mittelung** wählen (Standard: *Mittel aus 4*). Mehr Bilder = weniger Rauschen; das Tier muss
   dabei ruhig liegen.
4. **Aufnehmen**. Das Bild erscheint im Feld und wird sofort verarbeitet.

Unter **Kameraeinstellungen** lassen sich (auf Android) Fokusdistanz, Belichtung, Weißabgleich, ISO,
Zoom und Taschenlampe einstellen und mit **Aktuelle Einstellungen fixieren** sperren. Ein aktives Rig
stellt diese Werte beim nächsten Start automatisch wieder ein.

**Neues Exemplar** (oben rechts) leert beide Felder für das nächste Tier.

---

## 5. Prüfen: Maske und Orientierung

Unter **Prüfen & Landmarken** zeigt Wingmate für jedes Bild:

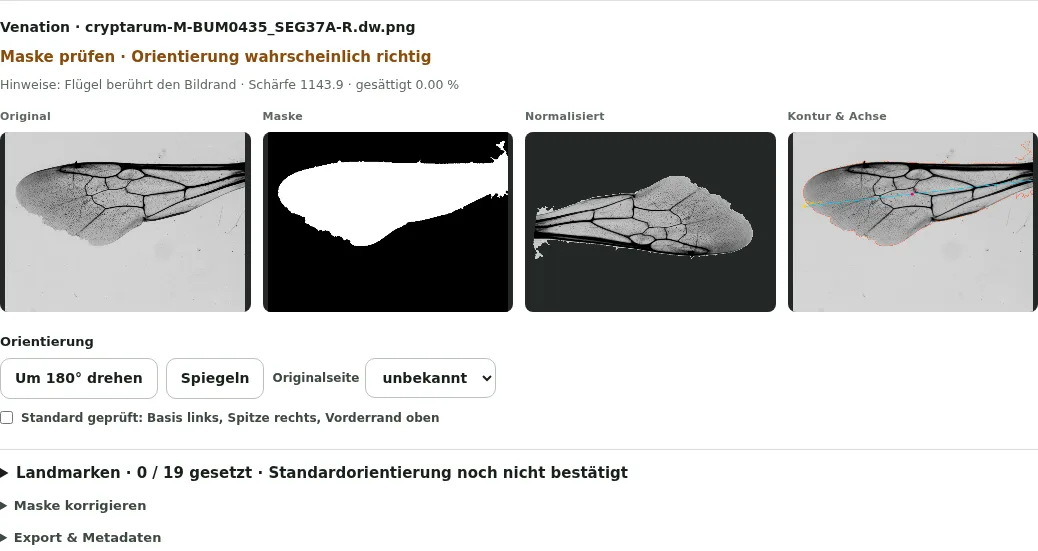
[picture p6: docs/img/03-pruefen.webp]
Prüfkarte mit Bildern und Orientierung


- eine **Einschätzung**, z. B. *Maske plausibel · Orientierung wahrscheinlich richtig*, oder
  *Prüfhinweise vorhanden* mit Hinweisen darunter (z. B. „Flügel berührt den Bildrand“);
- vier Ansichten: **Original**, **Maske** (weiß = erkannter Flügel), **Normalisiert** (ausgerichtet
  auf 1024 × 512 Pixel) und **Kontur & Achse**.

**Was Sie prüfen:**

1. **Maske:** Ist der ganze Flügel weiß und nichts anderes? Wenn nicht → *Maske korrigieren*
   aufklappen: die **Segmentierungsschwelle** ändern oder eine selbst korrigierte Schwarz-Weiß-Maske
   importieren. *Alle Korrekturen zurücksetzen* stellt den Ausgangszustand her.
2. **Orientierung** im Bild *Normalisiert*: **Basis links, Spitze rechts, Vorderrand oben.**
   - Falsch herum? **Um 180° drehen**.
   - Vorderrand unten? **Spiegeln**. (Linke und rechte Flügel sind Spiegelbilder; durch das
     Spiegeln werden sie vergleichbar.)
   - **Originalseite** (links/rechts) angeben, falls bekannt – sie bleibt dokumentiert.
3. Passt alles: **Standard geprüft** ankreuzen.
4. Bei Prüfhinweisen die **Freigabebegründung** ausfüllen: dokumentieren, warum die Aufnahme
   trotz Hinweis verwendbar ist. Ein plausibler Umriss allein belegt keine nutzbare Aderung.

Bei zwei Bildern (Venation + WIP) richtet Wingmate das WIP-Bild automatisch am Venationsbild aus
und zeigt die Überlagerung. Beide müssen **denselben Vorderflügel desselben Tieres** zeigen.
Der automatische Abgleich prüft nur die Kontur. Innere Adern vergleichen und die Bestätigung
unter der Überlagerung ankreuzen, bevor das Bildpaar freigegeben wird.

Weniger Gebrauchtes: *Export & Metadaten* (normalisiertes Bild, Maske, alle Transformationen) und
oben rechts *Weitere Aktionen* (Neu berechnen, Metadaten-Export, Landmarken als CSV, Achsen
und Rahmen einblenden). **Letztes Exemplar öffnen** steht unter den Aufnahmefeldern.

---

## 6. Landmarken setzen

**Landmarken** sind 19 feste Punkte an Aderkreuzungen. Ihre Lage beschreibt die Flügelform – das
ist die bewährteste Grundlage für die Bestimmung (geometrische Morphometrie). Ohne Landmarken
bestimmt Wingmate nur mit Bildmerkmalen. Deren Zuverlässigkeit muss für Ihre Arten und
Aufnahmebedingungen separat geprüft werden.

In der Prüfkarte des Venationsbildes **Landmarken** aufklappen:

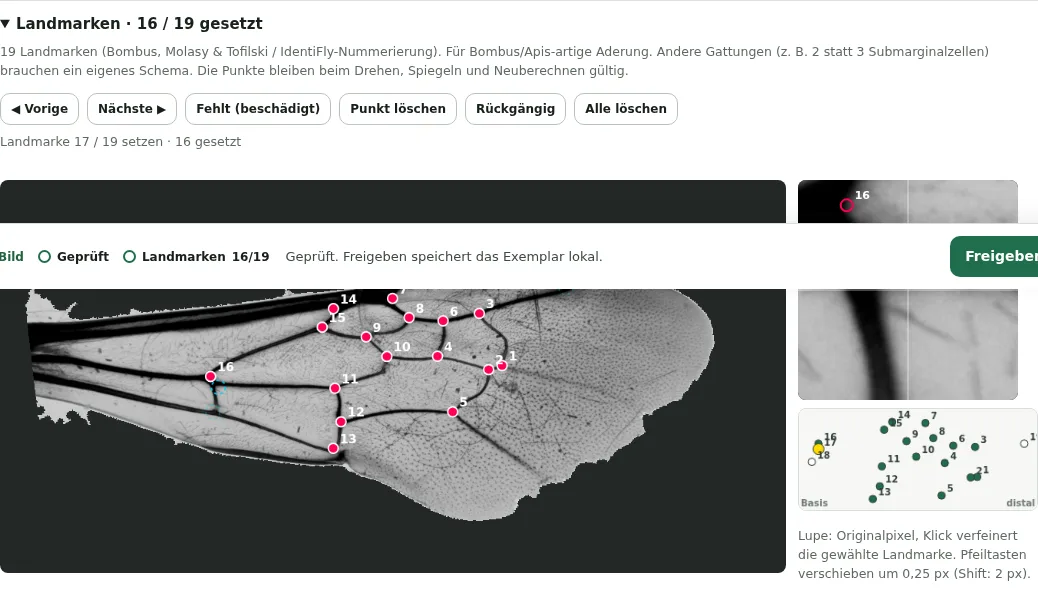
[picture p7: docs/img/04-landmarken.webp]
Landmarken-Editor mit Lupe und Übersicht


**So geht's:**

1. Oben steht, welche Landmarke dran ist (*Landmarke 17 / 19 setzen*). Die **Übersicht** rechts
   unten zeigt, wo sie beim mittleren Flügel liegt (gelb = aktuelle).
2. Im großen Bild **ungefähr auf die Stelle tippen**. Die Landmarke wird gesetzt, die nächste ist dran.
3. In der **Lupe** (Originalpixel, 6-fach vergrößert) **genau auf die Aderkreuzung klicken** –
   das verfeinert den Punkt und springt weiter.

**Hilfen:**

- Ab 2 Punkten zeigen **gestrichelte Kreise**, wo die nächsten Landmarken zu erwarten sind.
- Ab 4 Punkten werden Punkte **orange**, die stark vom üblichen Muster abweichen – meist vertauschte
  Nummern. Bei anderen Gattungen kann das auch normal sein.

**Korrigieren:**

- Einen Punkt **ziehen**, um ihn zu verschieben. (Nur Ziehen verschiebt – so lassen sich auch dicht
  beieinander liegende Landmarken wie 1/2 oder 16/17 setzen.)
- Einen gesetzten Punkt antippen, um ihn auszuwählen; in der Lupe verfeinern.
- **◀ Vorige / Nächste ▶**, **Punkt löschen**, **Rückgängig**, **Alle löschen**.
- **Fehlt (beschädigt):** Landmarke nicht bestimmbar. Unvollständige Sätze gehen nicht in die
  Formanalyse ein.

**Tastatur** (Bild vorher anklicken): Pfeiltasten verschieben um 0,25 px (mit Shift 2 px),
`n` / `p` nächste / vorige Landmarke, `Strg+Z` rückgängig, `Entf` Punkt löschen.

Die Punkte bleiben beim Drehen, Spiegeln und Neuberechnen erhalten.

**Schema:** Wingmate nutzt die 19 Landmarken des *Bombus*-Datensatzes von Molasy & Tofilski
(IdentiFly-Nummerierung). Es passt für Bombus/Apis-artige Aderung; Gattungen mit anderer Aderung
(z. B. zwei statt drei Submarginalzellen) brauchen ein eigenes Schema.

---

## 7. Freigeben – und dann: Referenz oder Bestimmung

Sind Maske und Orientierung geprüft, zeigt die Leiste **Freigeben**:

Leiste vor dem Freigeben

**Freigeben** speichert das Exemplar lokal (Originaldateien, Maske, normalisiertes Bild,
Transformation, Landmarken). Danach bietet die Leiste zwei Wege:

Leiste nach dem Freigeben

### a) Als Referenz speichern – wenn die Art sicher bekannt ist

**Als Referenz …** öffnet ein kurzes Formular:

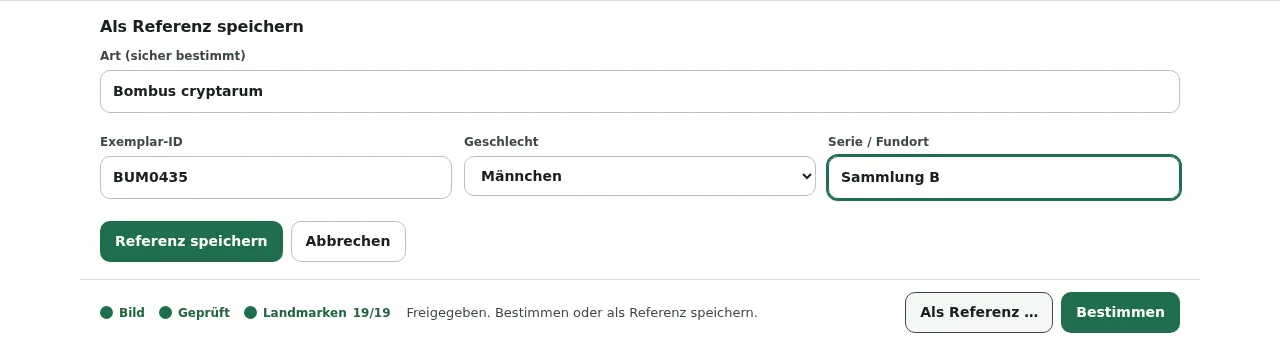
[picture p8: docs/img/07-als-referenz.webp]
Formular „Als Referenz speichern“


| Feld | Bedeutung |
| --- | --- |
| **Art** | Nur eintragen, wenn **sicher bestimmt** (z. B. genetisch oder durch Fachleute). |
| **Exemplar-ID** | Gleiche ID für **linken und rechten Flügel desselben Tieres**. So vergleicht die Auswertung nie ein Tier mit sich selbst. |
| **Geschlecht** | Weibchen / Männchen. Flügel unterscheiden sich zwischen den Geschlechtern. |
| **Serie / Fundort** | Sammlung, Fundort oder Aufnahmesitzung. Wichtig, um zu prüfen, ob die Bestimmung auch auf neuen Serien funktioniert (Kapitel 9). |

**Referenz speichern**. Danach **Neues Exemplar** für das nächste Tier.

### b) Bestimmen – wenn die Art gesucht ist

**Bestimmen** wechselt zum Bereich *Ergebnis*. Ist ein trainiertes Modell aktiv, heißt der Knopf
**Mit Modell bestimmen**.

Nach dem Freigeben geänderte Landmarken heben die Freigabe auf – dann erneut **Freigeben**.

---

## 8. Das Ergebnis lesen

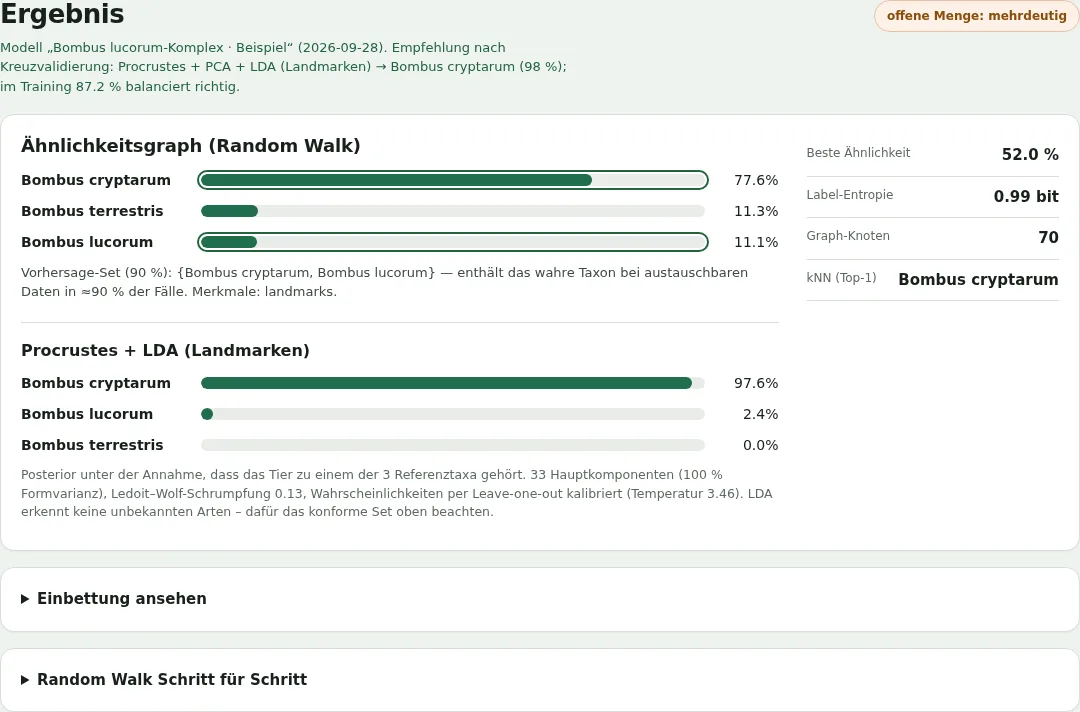
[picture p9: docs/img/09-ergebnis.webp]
Ergebnis mit Empfehlung, Ähnlichkeitsgraph und Procrustes + LDA


**Die Zeile ganz oben** ist die Empfehlung. Mit aktivem Modell steht dort, welches Standardverfahren das Modell
verwendet, seine Antwort und wie oft es im Training richtig lag, z. B.:
*Procrustes + PCA + LDA → Bombus cryptarum (98 %); im Training 87,2 % balanciert richtig.*

Darunter zwei Verfahren:

**Ähnlichkeitsgraph (Random Walk)** vergleicht das Tier mit allen Referenzen. Die Balken zeigen, wie
viel „Ähnlichkeit“ auf jede Art entfällt (bereinigt um die Zahl der Referenzen je Art). Dazu das
**Vorhersage-Set**: die Arten, die mit dem Exemplar vereinbar sind; grün umrandete Balken
gehören dazu. Im eingefrorenen Modell ist 90 % die angestrebte Abdeckung unter vergleichbaren
Aufnahmebedingungen und mit genügend unabhängigen Kalibrierungstieren. Die Live-Bestimmung
verwendet eine explorative Heuristik ohne diese Abdeckungsgarantie.

**Procrustes + LDA (Landmarken)** vergleicht nur die Flügelform. Die Prozentwerte sind
**temperaturkalibriert** anhand der Trainingsgruppen. Die Prozentwerte sind geschätzte
Konfidenzen; ihre Zuverlässigkeit muss an unabhängigen Tieren geprüft werden. Sie gelten aber
nur **unter der Annahme, dass das Tier zu einer Ihrer Referenzarten gehört**.

**Das Feld „offene Menge“** oben rechts beantwortet die Frage „Ist das überhaupt eine bekannte Art?“:

| Anzeige | Bedeutung |
| --- | --- |
| **eindeutig** | Nur eine Art passt. |
| **mehrdeutig** | Mehrere Arten passen; die Bestimmung ist nicht sicher (häufig bei nahe verwandten Arten). |
| **keiner Art ähnlich** | Das Exemplar ist untypischer als fast alle Referenzen jeder Art: mögliche neue Art, Aufnahmefehler oder Lücke in den Referenzen. |
| **nicht kalibriert** | Live-Bestimmung oder mindestens eine Art mit weniger als 9 getrennten Kalibrierungstieren. Eine belastbare Entscheidung über unbekannte Arten ist damit nicht möglich. |

**So entscheiden Sie:** Stimmen Empfehlung, Ähnlichkeitsgraph und LDA überein und ist die offene
Menge *eindeutig*, ist das Ergebnis gut gestützt. Widersprechen sie sich oder ist sie *mehrdeutig*,
das Tier als unsicher behandeln. Warnungen wie „Nur 3 Exemplar(e) im kleinsten Taxon“ ernst nehmen.

Rechts stehen Kennzahlen (beste Ähnlichkeit, Entropie, Knoten, kNN-Vergleich). Eingeklappt:
**Einbettung ansehen** (2D-Karte der Referenzen, keine Stammbaumdarstellung) und **Random Walk Schritt
für Schritt** (Animation des Rechenwegs).

---

## 9. Modell trainieren

Unter **Veröffentlichtes Startmodell (3 Bombus-Arten)** lässt sich ein optionales
Modell für **B. cryptarum, B. lucorum und B. terrestris** laden. Es benötigt die
19 manuellen Bombus-Landmarken und verändert keine eigenen Bildreferenzen.
Quelle, Zitation, ODbL-1.0 und die numerischen Referenzdaten sind dort verlinkt;
der Modellexport behält diese Angaben. Das Startmodell hat keinen unabhängigen
Abschlusstest. Für cryptarum reichen die Kalibrierungstiere nicht zum verlässlichen
Ausschluss unbekannter Arten. Für andere Arten ein eigenes Modell verwenden.

Ohne Modell rechnet Wingmate jede Bestimmung **live** aus den aktuellen Referenzen, bevorzugt
mit Landmarken-LDA und sonst Distanz-kNN. Jedes Referenztier steuert einen Prototyp bei. Mit
**Referenzen → Modell trainieren** wird daraus ein festes **Modell** mit Entwicklungsbewertung:

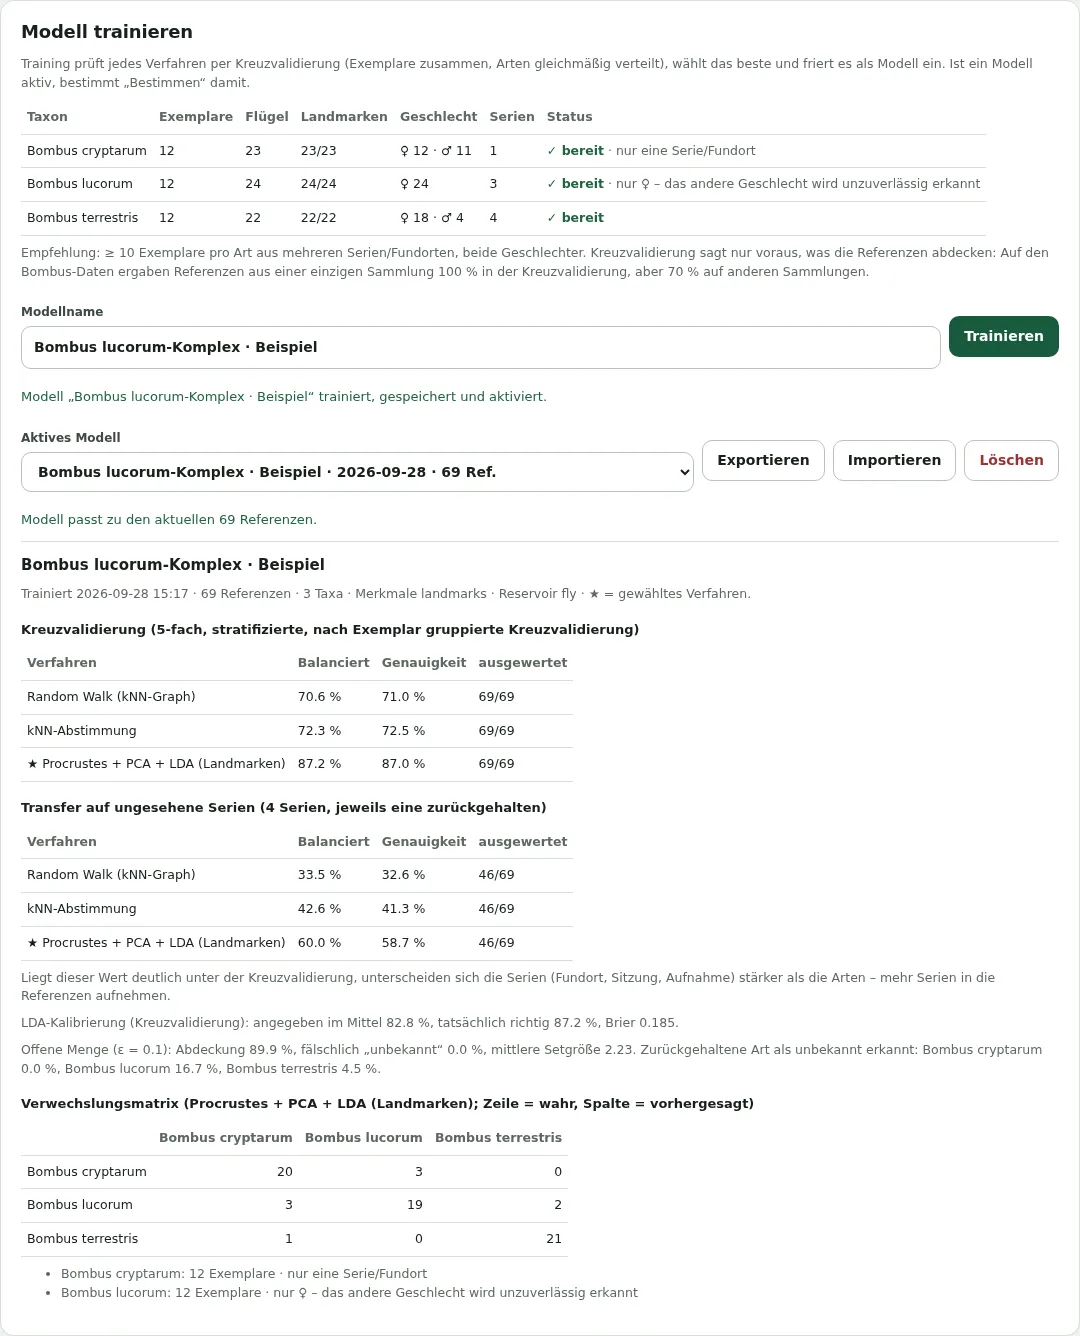
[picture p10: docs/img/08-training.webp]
Training: Bereitschaft, Bericht und Verwechslungsmatrix


**1. Bereitschaft prüfen.** Unter **Referenzbereitschaft & Trainingsverfahren** zeigt die Tabelle je Art Exemplare, Flügel, Landmarken, Geschlecht und
Serien:

- ✓ **bereit:** mindestens 10 Exemplare
- ⚠ weniger als 10 · ✗ weniger als 5 Exemplare
- Hinweise wie **nur ♀** oder **nur eine Serie/Fundort** bedeuten, dass das Modell andere
  Geschlechter bzw. neue Fundorte schlechter erkennen wird.

Bei einer neu freigegebenen Aufnahme wird das Feld **Exemplar-ID** geleert. Für weitere
Flügel desselben Tieres dieselbe stabile ID erneut eingeben; für ein neues Tier eine neue ID.

**2. Trainieren.** Namen und **Eingabemodus** wählen, **Trainieren**. Alle Referenzen müssen
die gewählten Merkmale haben. „Nur Landmarken“ erlaubt eine Formanalyse ohne die
experimentelle WIP-Fusion. Wingmate prüft alle Verfahren mit derselben
**Kreuzvalidierung**: Die Referenzen werden fünfmal aufgeteilt, jedes Mal wird ein Fünftel
zurückgehalten und bestimmt. Alle Flügel eines Tieres bleiben dabei zusammen. Das Standardverfahren ist Landmarken-LDA, bei fehlenden Landmarken Distanz-kNN (★).
Die anderen Verfahren dienen dem Vergleich. Das Ergebnis wird eingefroren. Ausrichtung, Skalierung und PCA/LDA werden
in jedem Trainingsfold neu angepasst. Separate Tiere dienen ausschließlich der Kalibrierung
(standardmäßig 20 % je Art). Die angezeigten Entwicklungswerte ersetzen keinen unabhängigen
Abschlusstest. Zehn Referenztiere bedeuten deshalb noch keine ausreichende Kalibrierung.

**3. Den Bericht lesen:**

- **Kreuzvalidierung:** Jedes Tier zählt einmal; seine unterschiedlichen Flügel entscheiden
  per Mehrheit (Gleichstand nach Taxonname). Flügelwerte bleiben getrennt im Modellexport.
  Die 95-%-Intervalle resampeln die gespeicherten Tierergebnisse, keine vollständigen neuen Modelle. *Balanciert* heißt:
  jede Art zählt gleich viel, auch wenn eine Art viel mehr Referenzen hat.
- **Transfer auf ungesehene Serien** (nur wenn alle Referenzen eine Serie haben): Jeweils eine
  ganze Serie wird zurückgehalten. **Liegt dieser Wert deutlich unter der Kreuzvalidierung** (im Bild
  60 % statt 87 %), unterscheiden sich Ihre Serien stärker als die Arten – mehr Serien sammeln.
  Diese Zahl ist die ehrlichere Schätzung für neue Fundorte.
- **LDA-Kalibrierung:** angegebene vs. tatsächliche Trefferquote – sollten nahe beieinander liegen.
- **Offene Menge:** wie oft die wahre Art im Vorhersage-Set war und wie oft bekannte Tiere
  fälschlich als „unbekannt“ abgewiesen wurden. Die Erkennung unbekannter Arten benötigt einen
  separaten Test mit vollständig zurückgehaltenen Taxa.
- **Verwechslungsmatrix:** Zeile = wahre Art, Spalte = Vorhersage. Zahlen außerhalb der Diagonale
  zeigen, welche Arten verwechselt werden.

**4. Modelle verwalten.** Unter **Aktives Modell** wählen (oder *Kein Modell* für die
Live-Bestimmung), unter **Modelle verwalten** **Exportieren** (eine JSON-Datei, z. B. zum Weitergeben),
**Importieren** oder **Löschen** wählen.

Modelle aus früheren Versionen benötigen neues Training (`wingmate-model-3`). Aktuelle
Bildreferenzen bleiben verwendbar. Ein Modell ändert sich nicht von selbst. Kommen neue Referenzen dazu, erscheint
*„Referenzen haben sich seit dem Training geändert“* → neu trainieren.

---

## 10. Gute Referenzen sammeln

Die Bestimmung hängt von Qualität und Vielfalt der Referenzen ab. Die lokalen
Landmarken-Benchmarks sind Entwicklungsvergleiche, keine unabhängigen Genauigkeitsnachweise:

- **Mindestens 10 Exemplare pro Art** ist ein Bereitschaftshinweis. Die nötige Datenmenge
  hängt von Artengruppe und Aufnahmebedingungen ab. Für die p-Wert-Auflösung bei ε = 0,1
  benötigt das eingefrorene Modell mindestens neun unabhängige **Kalibrierungstiere** je Art,
  zusätzlich zu den Trainingstieren.
- **Mehrere Serien/Fundorte pro Art.** Prüfen Sie den Transferbericht. Neue Aufnahmesitzungen
  und Sammlungen können deutlich schlechter erkannt werden als die Entwicklungsdaten.
- **Beide Geschlechter.** Nur Weibchen als Referenz kostete bei Männchen rund 6 Prozentpunkte.
- **Unterschiedliche Tiere, nicht Wiederholungen:** Linker und rechter Flügel desselben Tieres
  zählen als *ein* Exemplar (gleiche Exemplar-ID).
- **Immer gleich aufnehmen:** dasselbe Rig, dieselbe Einstellung, dieselbe Orientierung.
- **Nur sicher bestimmte Tiere** als Referenz. Eine falsche Referenz schadet mehr als eine fehlende.

---

## 11. Daten sichern

Alles liegt **nur in diesem Browser auf diesem Gerät**:

| Daten | Ort | Sichern mit |
| --- | --- | --- |
| Referenzen | Browser-Speicher (localStorage) | *Referenzen → Sammlung → Sammlung verwalten → Exportieren* |
| Freigegebene Exemplare (Originale, Masken, Landmarken) | Browser-Datenbank (IndexedDB) | *Prüfen → Weitere Aktionen → Metadaten & Maske exportieren*, *Landmarken als CSV* |
| Modelle | IndexedDB | *Modell trainieren → Exportieren* |
| Rig-Profile | IndexedDB | *Einstellungen → Aufnahme-Rig → Exportieren* |

Browserdaten löschen, privates Surfen oder ein anderer Browser bedeuten: **die Daten sind weg.**
Deshalb **Referenzen regelmäßig exportieren**. Auf einem anderen Gerät über *Importieren* einlesen;
bereits vorhandene Referenzen werden dabei nicht doppelt angelegt.

Die Landmarken-CSV (`file,x1,y1,…,x19,y19`, Originalpixel) lässt sich in MorphoJ, geomorph oder
IdentiFly weiterverwenden.

---

## 12. Einstellungen

- **Aufnahme-Rig:** siehe Kapitel 3.
- **Rechenraum (Reservoir):** wie der Ähnlichkeitsgraph die Merkmale vergleicht. Standard ist
  *Direkte Merkmale*. *FlyHash* (nach dem Riechsystem der Fruchtfliege) und
  *Dichte Zufallsprojektion* sind experimentelle Vergleichsverfahren. **Für normale Nutzung nichts ändern.** Änderungen gelten für die
  Live-Bestimmung und neues Training, nicht für ein bereits trainiertes Modell.
- **FlyWire-Subgraph importieren:** experimentell, für Forschungsfragen zum echten
  Fliegen-Konnektom; wird nicht in Modelle eingefroren.
- **App:** Installationshinweise.
- **Methodik:** Kurzbeschreibung der Verfahren. Ehrlich festgehalten: Auf den getesteten
  *Bombus*-Daten ist die Landmarken-Methode (Procrustes + LDA) besser als der Ähnlichkeitsgraph, und
  FlyHash bringt gegenüber den Vergleichsverfahren keinen Vorteil.

---

## 13. Fehlerbehebung

| Problem | Lösung |
| --- | --- |
| **„Kamera nur über HTTPS oder localhost verfügbar“** | Die App über <https://hofda.github.io/wingmate/> oder `npm run serve:https` öffnen. |
| Kamera startet nicht | Kamerazugriff für die Seite im Browser erlauben; andere Apps, die die Kamera nutzen, schließen. |
| **„Keine manuellen Kamerasteuerungen verfügbar“** | Normal auf iPhone/Safari und vielen Webcams. Rig kalibrieren und auf die *Rig-Abweichung* achten, oder *Foto wählen* → Kamera-App mit AE/AF-Sperre. |
| **„Rig … nicht angewendet: Bild … Profil …“** | Das Bild hat eine andere Auflösung als das Rig-Profil (andere Kamera, anderer Zoom, Foto aus der Kamera-App). Mit der Live-Kamera aufnehmen oder das Rig für diese Auflösung neu kalibrieren. |
| **„Licht/Hintergrund weicht vom Rig-Profil ab“** | Rig verrutscht, Lampe geändert oder Umgebungslicht. Aufbau prüfen; bei dauerhafter Änderung neu kalibrieren. |
| **„Prüfhinweise vorhanden“ / Flügel nicht richtig erkannt** | *Maske korrigieren*: Schwelle ändern oder korrigierte Maske importieren. Mit kalibriertem Rig tritt das seltener auf. |
| **„Überbelichtung im Flügel“** | Belichtung verringern bzw. Licht dimmen und neu aufnehmen. |
| **Freigeben** bleibt grau | Bei jedem Bild **Standard geprüft** ankreuzen. Bei Prüfhinweisen zusätzlich eine Freigabebegründung eingeben; bei Bildpaaren denselben Flügel und innere Entsprechung bestätigen. |
| **Bestimmen** fehlt | Erst **Freigeben**. |
| **„… keine gemeinsamen Merkmale“** | Exemplar und Referenzen wurden unterschiedlich erfasst, z. B. Referenzen nur mit Landmarken. Für dieses Exemplar alle Landmarken setzen und neu freigeben. |
| **„Das Modell braucht Merkmale, die dieser Aufnahme fehlen“** | Das aktive Modell wurde z. B. mit Landmarken trainiert: Landmarken vollständig setzen (und Orientierung bestätigen) – oder ein anderes Modell wählen. |
| Landmarken lassen sich nicht setzen | Die Karte **Landmarken** gibt es nur am Venationsbild (ohne Venation am WIP-Bild). Zum Verschieben ziehen, zum Setzen tippen. |
| **„offene Menge: nicht kalibriert“** | Ein Modell mit separaten Kalibrierungstieren trainieren. Für ε = 0,1 sind mindestens neun Kalibrierungstiere je Art nötig; doppelte Flügel erhöhen diese Zahl nicht. |
| Referenzen nach Neustart weg | Browserdaten wurden gelöscht oder ein anderer Browser/privates Fenster benutzt. Export einlesen (Kapitel 11). |
| „Alte Referenzen (nur Embeddings, Format v1)“ | Referenzen einer sehr frühen Version – nicht mehr vergleichbar. Mit denselben Bildern neu anlegen. |
| Neue Version wird nicht angezeigt | Auf **Update laden** klicken oder alle App-Fenster schließen und neu öffnen. |

---

## 14. Begriffe

| Begriff | Erklärung |
| --- | --- |
| **Venation** | Flügeladerung, im Durchlicht aufgenommen. |
| **WIP** | *Wing Interference Patterns* – Schillerfarben dünner Flügelmembranen, auf schwarzem Grund im Auflicht sichtbar. |
| **Maske** | Die Fläche, die Wingmate als Flügel erkannt hat. |
| **Standardansicht** | Basis links, Spitze rechts, Vorderrand oben; alle Flügel werden so ausgerichtet. |
| **Landmarke** | Fester, wiederfindbarer Punkt auf dem Flügel (meist eine Aderkreuzung). |
| **Procrustes** | Verfahren, das Landmarken-Sätze in Lage, Größe und Drehung angleicht, sodass nur die Form verglichen wird. |
| **LDA** | Lineare Diskriminanzanalyse – klassisches Verfahren, das Arten anhand der Form trennt. |
| **Referenz** | Sicher bestimmtes Exemplar, mit dem verglichen wird. |
| **Exemplar** | Ein Tier. Mehrere Flügel desselben Tieres = ein Exemplar. |
| **Serie** | Sammlung, Fundort oder Aufnahmesitzung. |
| **Kreuzvalidierung** | Prüfung, bei der ein Teil der Referenzen zurückgehalten und bestimmt wird. |
| **Balancierte Genauigkeit** | Mittlere Trefferquote über alle Arten; jede Art zählt gleich. |
| **Vorhersage-Set / offene Menge** | Arten, die mit dem Exemplar vereinbar sind. Im eingefrorenen Modell: Zielabdeckung 90 % bei gültiger Kalibrierung und vergleichbaren Tieren; live nur Heuristik. Leer = keiner bekannten Art ähnlich. |
| **Kalibriert** | Angegebene Wahrscheinlichkeiten entsprechen ungefähr den tatsächlichen Trefferquoten. |
| **Rig** | Fester Aufnahmeaufbau aus Smartphone, Optik, Licht und Hintergrund. |
| **Flat-Field-Korrektur** | Ausgleich ungleichmäßiger Beleuchtung anhand eines leeren Referenzbildes. |
| **Modell** | Eingefrorenes Ergebnis eines Trainings; bestimmt, bis Sie es wechseln oder neu trainieren. |
| **FlyHash / Reservoir** | Von der Fruchtfliege inspirierte Art, Merkmale zu vergleichen (experimentell). |

---

*Screenshots: echte App mit echten Flügeldaten (Molasy & Tofilski, Zenodo 19703357), erzeugt mit
`scripts/manual-screenshots.cjs`.*

## Apis mellifera: Referenzsammlung

Im Trainingsbereich lässt sich die veröffentlichte Apis-Referenzsammlung
herunterladen, auch offline nach der ersten vollständigen App-Installation.
Sie enthält je einen Flügel aus 1.342 Kolonien in zehn Ländern sowie Zitation
und ODbL-1.0-Angaben. Die unveränderten numerischen Originaldateien liegen
im Repository unter `models/apis-source/originals/`.

Die Sammlung nutzt das separate Landmarkenschema nach Nawrocka (2018) und
ist kein importierbares Artenmodell oder persönlicher Referenzexport. Für
ein gemeinsames Apis/Bombus-Modell muss die anatomische Zuordnung zuerst
geprüft werden. Einzelheiten, Datenformat und Quellen stehen im
[Datensatz-README](../models/apis-source/README.md).

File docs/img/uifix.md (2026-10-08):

# UI review and remediation

Reviewed 2026-10-08. The seven reported issues have been addressed in the current working tree.

| Reported problem | Change |
| --- | --- |
| Oversized, bold form controls | Inputs and selects use regular weight and 14 px on desktop. Mobile retains 16 px to avoid focus zoom. Button sizing is defined in one base rule. |
| Too many competing actions | After loading, “Foto wählen” becomes a secondary “Bild ersetzen” action. Model export/import/delete sit under “Modelle verwalten”; collection export/delete sit under “Sammlung verwalten”. |
| Duplicate wing preview and upload dead space | The loaded upload preview is hidden; the original remains in review alongside the mask, normalized image and contour overlay. Capture controls become compact, bringing review closer. Replacement supports keyboard activation and selecting the same file again. |
| Long header status | A short status chip shows offline readiness. Its accessible description and tooltip retain the full explanation. Update instructions appear in App settings. |
| Overweighted mask warnings | The verdict uses neutral text. The compact review reason follows the images and orientation controls. Actual warnings, mandatory reasons and paired-image confirmation remain enforced. |
| Duplicate empty state and dense training introduction | The empty collection count/instructions are hidden while the main empty state is visible. Training starts with a short explanation and controls; readiness and protocol details are expandable. |
| Contradictory CSS patches | Product overrides are merged into the base component rules; identical media queries and duplicate selectors within each scope are consolidated. Responsive variants remain at the end. |

Verification: Node test suite, pipeline audit probes, and Chrome checks at desktop/mobile widths. Browser checks exercise empty references, model-management disclosure, typography, image loading, review reasons, acceptance, same-file replacement and all four views without horizontal overflow. The existing PWA smoke checks cover offline reload, persisted data, worker availability, updates and subdirectory hosting.

Research validation remains tracked in [pipeline-audit.md](../pipeline-audit.md); these interface changes do not establish biological identification accuracy.

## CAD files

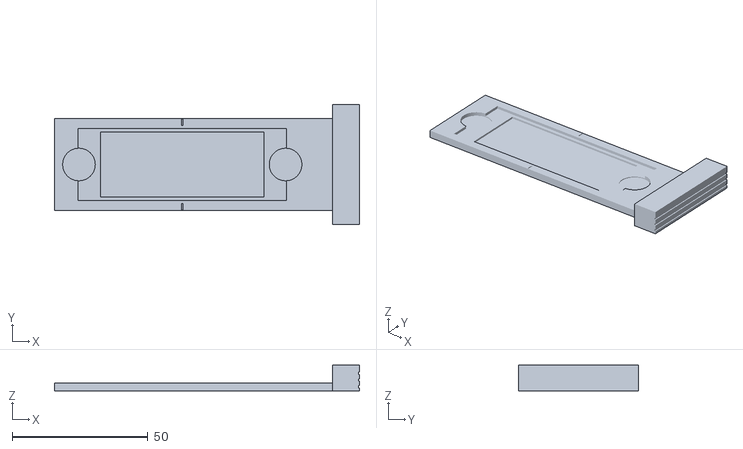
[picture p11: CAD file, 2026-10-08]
rig/stl/carrier_wip.stl
112.2 x 44.0 x 9.50

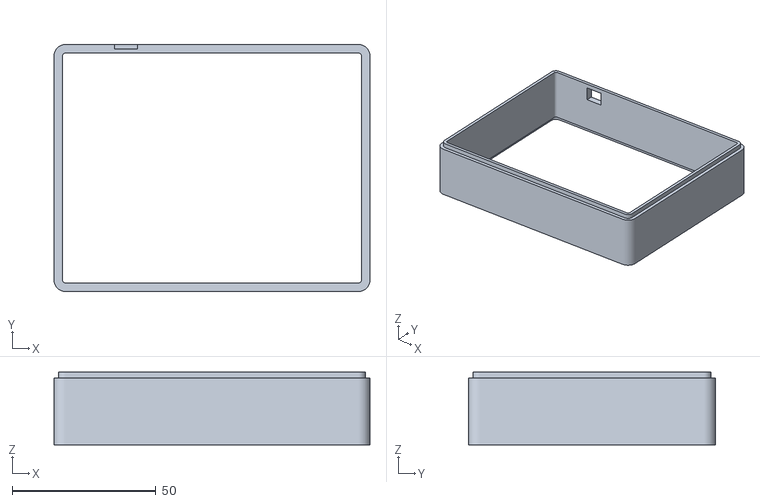
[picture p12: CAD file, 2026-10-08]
rig/stl/tower.stl
110.0 x 86.0 x 25.4

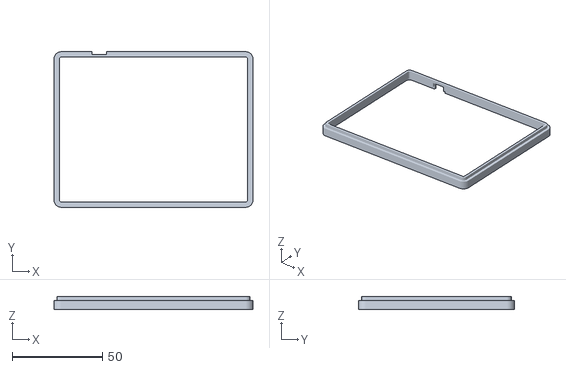
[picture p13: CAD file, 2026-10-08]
rig/stl/spacer.stl
110.0 x 86.0 x 7.00

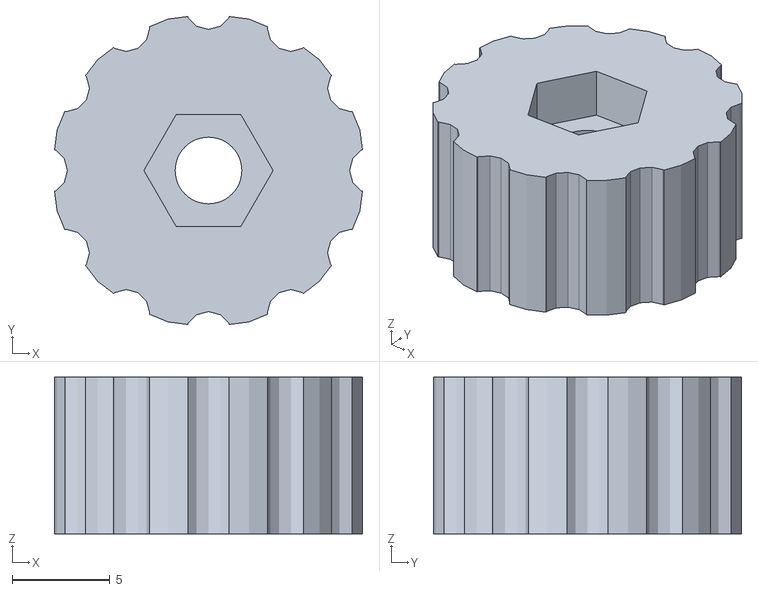
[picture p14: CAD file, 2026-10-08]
rig/stl/knob.stl
15.7 x 15.7 x 8.00

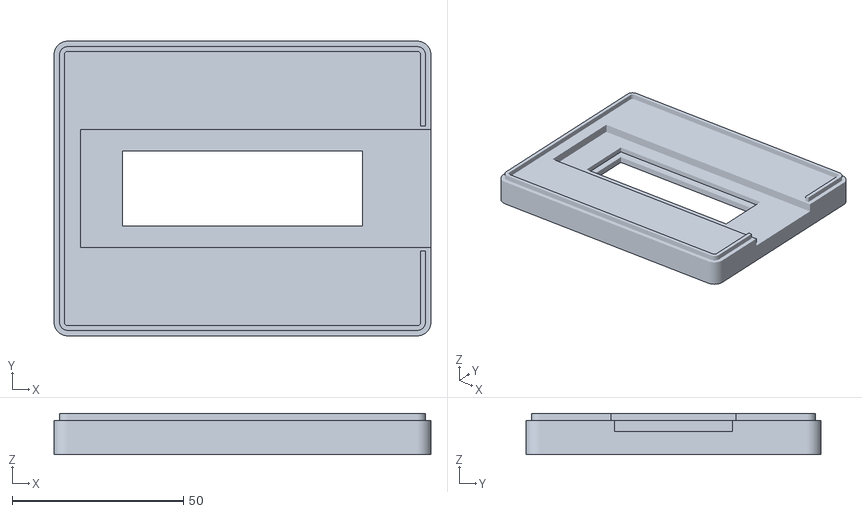
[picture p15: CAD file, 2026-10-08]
rig/stl/stage.stl
110.0 x 86.0 x 12.0

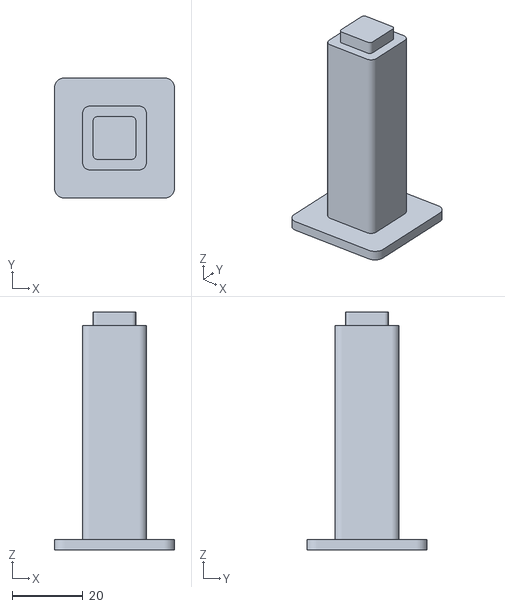
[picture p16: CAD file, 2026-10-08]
rig/stl/leg.stl
34.0 x 34.0 x 67.2

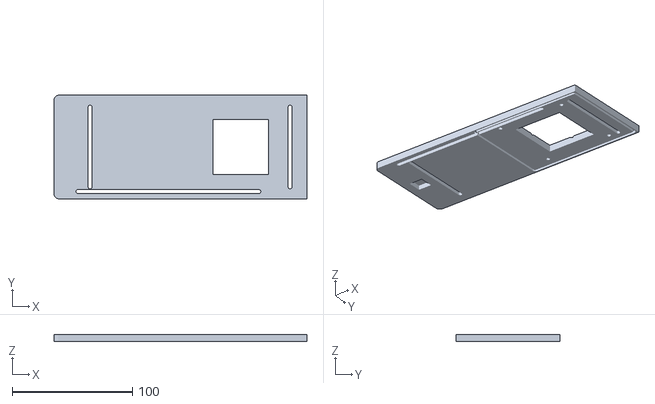
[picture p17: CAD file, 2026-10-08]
rig/stl/deck.stl
210.0 x 86.0 x 6.00

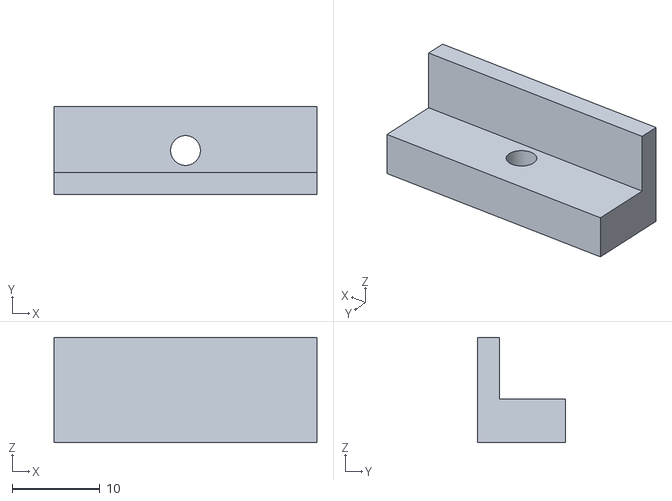
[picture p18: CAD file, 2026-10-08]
rig/stl/stop.stl
30.0 x 10.0 x 12.0

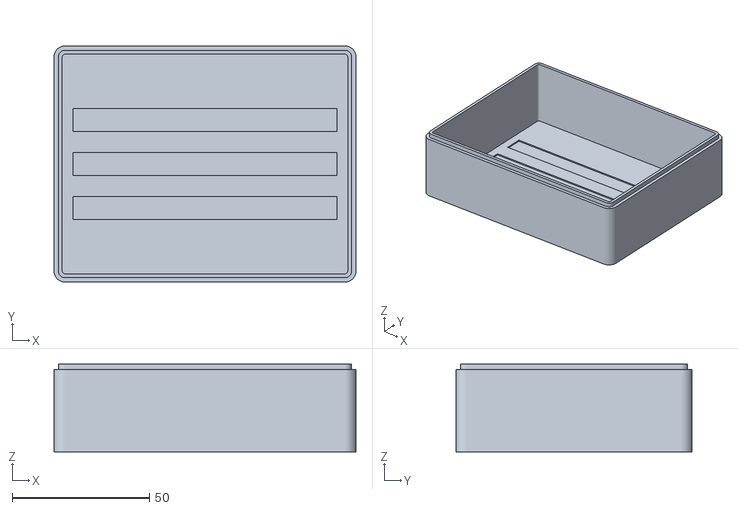
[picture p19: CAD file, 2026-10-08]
rig/stl/base.stl
110.0 x 86.0 x 32.0

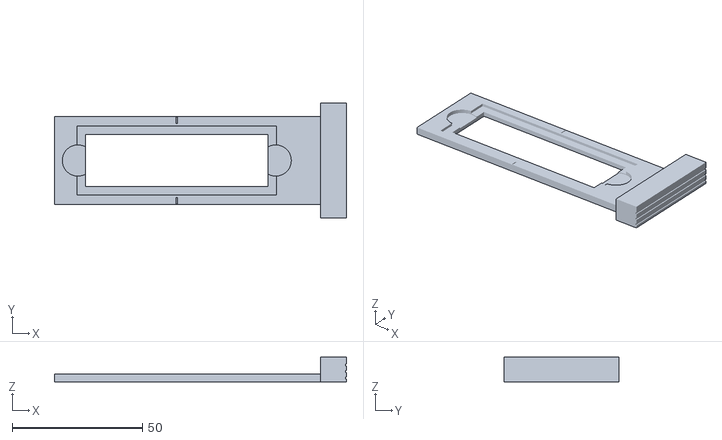
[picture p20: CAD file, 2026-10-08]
rig/stl/carrier.stl
112.2 x 44.0 x 9.50

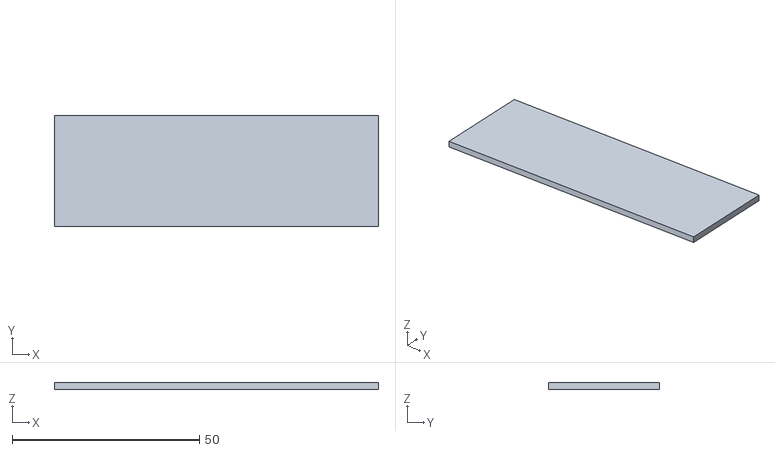
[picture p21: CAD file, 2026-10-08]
rig/stl/diffuser.stl
86.6 x 29.6 x 1.80

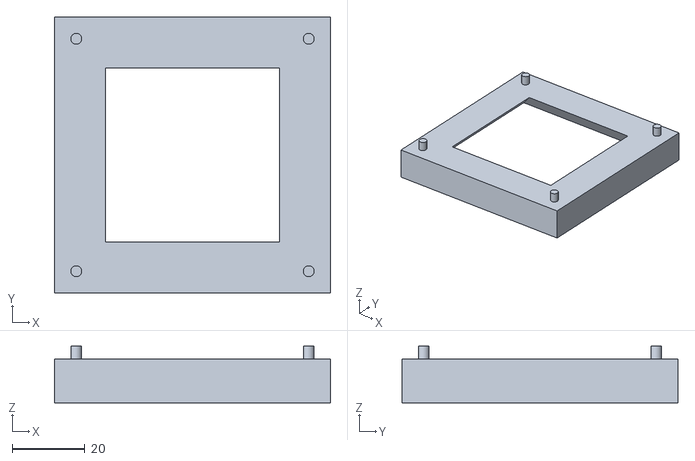
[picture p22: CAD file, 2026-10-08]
rig/stl/ring.stl
76.0 x 76.0 x 15.6

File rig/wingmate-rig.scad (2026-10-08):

// Wingmate rig – 3D-printable smartphone imaging box for bee forewings.
//
// Stack (bottom to top): base (LED light box) -> stage (slide drawer channel,
// diffuser pocket) -> tower (dark chamber; height = working distance) ->
// [spacer frames] -> deck (phone plate with camera window, stop slots, leg).
// Two drawers: "carrier" (window, transmitted light = venation) and
// "carrier_wip" (solid black, flock recess = wing interference patterns).
// "ring" is an experimental WIP light ring hung under the deck.
//
// Coordinates: x = long axis (drawer slides in from +x), y = depth, z = up,
// origin at the centre of the base underside. Units: mm.
// Render one part:  openscad -D 'part="base"' -o base.stl wingmate-rig.scad
// All parts:        rig/build.sh

/* [Part] */
part = "assembly"; // [assembly, exploded, section, base, stage, carrier, carrier_wip, tower, spacer, deck, leg, stop, knob, ring, diffuser]

/* [Optics – measure your phone] */
// Lens-to-wing distance. iPhone macro (ultra-wide) focuses from ~20 mm; closer = more
// pixels on the wing. Increase with spacer frames if the phone does not focus.
working_distance = 25;
// How far the camera bump protrudes from the phone back.
camera_bump = 4.5;
// Camera window in the deck (must clear the whole camera bump).
window_size = [46, 46];

// Spacer frames (5 mm each) between tower and deck add to the working distance
// without reprinting the tower. Reprint the leg after changing this.
spacer_count = 0; // [0:4]

/* [Phone deck] */
// Deck extends beyond the box on the -x side so the phone body is supported.
deck_extension = 100;
deck_thickness = 6;
// Support leg under the far end of the deck.
with_leg = true;

/* [Box] */
outer = [110, 86];
wall = 3.0;
base_height = 30;
floor_thickness = 2;
stage_thickness = 10;
corner_radius = 4;

/* [Slide and diffuser] */
// ISO 8037 slide 76 x 26 x 1 mm (US slides 75 x 25 also fit).
slide = [76, 26, 1.0];
// Diffuser strip, slid into the stage from the -x side (2 mm opal acrylic or printed).
diffuser = [87, 30, 2.0];
// Light window under the slide (stage and transmitted-light carrier). As large as the
// slide allows: the ultra-wide camera sees far more than the slide at 25 mm.
light_window = [70, 22];
led_strip_width = 8;

/* [Fit] */
tol = 0.25;       // clearance per side for sliding / stacking fits
lip_w = 1.4;      // stacking lip width (inner part of the wall top)
lip_h = 2.0;
$fn = 48;

// ---------- derived ----------
W = outer[0];
D = outer[1];
stage_z = base_height;                       // stage bottom
stage_top = stage_z + stage_thickness;       // = tower bottom
channel_depth = 3.2;
carrier_t = 3.0;
carrier_w = 34;                              // drawer width (y)
channel_w = carrier_w + 2 * tol;
carrier_stop_x = -47;                        // drawer left end when fully inserted
slide_top = stage_top - channel_depth + carrier_t - 1.1 + slide[2]; // slide pocket 1.1 deep
wing_z = slide_top + 0.17;                   // cover slip
tower_height = working_distance + camera_bump + wing_z - stage_top - deck_thickness;
spacer_height = 5;
tower_top = stage_top + tower_height;
deck_z = tower_top + spacer_count * spacer_height;   // deck underside
effective_working_distance = working_distance + spacer_count * spacer_height;
deck_x0 = -W / 2 - deck_extension;
assert(tower_height > 12, "Arbeitsabstand zu klein für diesen Aufbau");

// ---------- helpers ----------
module rounded(size, r = corner_radius) {
  // size = [x, y, z], centred in x/y, z from 0
  linear_extrude(size[2])
    offset(r) square([size[0] - 2 * r, size[1] - 2 * r], center = true);
}
module lip() {
  // Stacking lip on top of a part: inner half of the wall.
  difference() {
    rounded([W - 2 * (wall - lip_w), D - 2 * (wall - lip_w), lip_h], corner_radius - (wall - lip_w));
    translate([0, 0, -1]) rounded([W - 2 * wall, D - 2 * wall, lip_h + 2], corner_radius - wall);
  }
}
module lip_recess() {
  // Matching groove in the underside of the part above (with clearance).
  translate([0, 0, -1]) difference() {
    rounded([W - 2 * (wall - lip_w) + 2 * tol, D - 2 * (wall - lip_w) + 2 * tol, lip_h + 0.2 + 1], corner_radius - (wall - lip_w) + tol);
    translate([0, 0, -1]) rounded([W - 2 * wall - 2 * tol, D - 2 * wall - 2 * tol, lip_h + 4], corner_radius - wall - tol);
  }
}
module frame(h) {
  // Open wall ring with outer size W x D.
  difference() {
    rounded([W, D, h]);
    translate([0, 0, -1]) rounded([W - 2 * wall, D - 2 * wall, h + 2], corner_radius - wall);
  }
}

// ---------- parts ----------
// Light box. Print in WHITE: the inside works as a reflector.
module base() {
  difference() {
    rounded([W, D, base_height]);
    translate([0, 0, floor_thickness]) rounded([W - 2 * wall, D - 2 * wall, base_height], corner_radius - wall);
    // Shallow guides for three LED strip rows (x direction).
    for (y = [-16, 0, 16])
      translate([0, y, floor_thickness - 0.3]) cube([W - 2 * wall - 8, led_strip_width + 0.4, 0.62], center = true);
    // Cable exit, back wall.
    translate([W / 2 - 20, D / 2 - wall / 2, floor_thickness + 3]) cube([10, wall + 2, 6], center = true);
  }
  translate([0, 0, base_height]) lip();
}

// Stage: diffuser pocket from below, light window, drawer channel on top.
// Print in WHITE, top side up.
module stage() {
  difference() {
    union() {
      rounded([W, D, stage_thickness]);
      translate([0, 0, stage_thickness]) difference() {
        lip();
        // Lip interrupted where the drawer passes under the tower wall.
        translate([W / 2 - wall, 0, lip_h / 2]) cube([wall * 3, channel_w + 2, lip_h + 2], center = true);
      }
    }
    lip_recess();
    // Diffuser slot, entered from the -x face; the diffuser rests on the
    // edges of the light window and ends flush with the face.
    translate([-W / 2 - 1, -(diffuser[1] / 2 + tol), lip_h + 0.4]) cube([diffuser[0] + 1 + tol, diffuser[1] + 2 * tol, diffuser[2] + 0.4]);
    translate([-W / 2, 0, lip_h + 0.4 + diffuser[2] / 2]) cylinder(r = 7, h = diffuser[2] + 0.4 + 2, center = true); // finger notch
    // Light window.
    cube([light_window[0], light_window[1], 3 * stage_thickness], center = true);
    // Drawer channel, open to +x, closed at the stop.
    // (extends 1 mm upwards so the floor lies exactly at channel_depth)
    translate([(carrier_stop_x - 0.2 + W / 2 + 1) / 2, 0, stage_thickness - channel_depth / 2 + 0.5])
      cube([W / 2 + 1 - (carrier_stop_x - 0.2), channel_w, channel_depth + 1], center = true);
  }
}

// Drawer. wip = false: light window (venation). wip = true: solid, print BLACK,
// with a recess for adhesive black flock under the slide.
module carrier(wip = false) {
  body = W / 2 - carrier_stop_x;                  // stop to outer wall face
  pocket = [slide[0] + 2 * tol + 0.1, slide[1] + 2 * tol + 0.1, 1.1];
  difference() {
    union() {
      translate([carrier_stop_x, -carrier_w / 2, 0]) cube([body + 0.2, carrier_w, carrier_t]);
      // Handle flange: pull grip, stop against the wall, and light seal over the
      // channel opening. Starts at the drawer underside so the part prints flat.
      translate([W / 2 + 0.2, -22, 0]) cube([10, 44, 9.5]);
    }
    // Slide pocket, centred on the optical axis.
    translate([0, 0, carrier_t - pocket[2] / 2 + 0.5]) cube(pocket + [0, 0, 1], center = true);
    // Finger notches to lift the slide out.
    for (s = [-1, 1]) translate([s * (slide[0] / 2), 0, carrier_t]) cylinder(r = 6, h = 3, center = true);
    if (!wip) cube([light_window[0], light_window[1] - 2, 20], center = true);
    else translate([0, 0, carrier_t - pocket[2] - 0.4 + 0.01]) cube([60, 24, 0.8], center = true);
    // Centre marks (x and y) for aiming the camera.
    for (s = [-1, 1]) {
      translate([s * (pocket[0] / 2 + 3), 0, carrier_t]) cube([4, 0.6, 0.8], center = true);
      translate([0, s * (pocket[1] / 2 + 2.2), carrier_t]) cube([0.6, 2.4, 0.8], center = true);
    }
    // Grip ridges on the handle.
    for (z = [1.5 : 2.5 : 8]) translate([W / 2 + 10.4, 0, z]) cube([1.2, 46, 0.8], center = true);
  }
}

// Dark chamber. Print in BLACK (matte). Height follows from working_distance.
module tower(h = tower_height) {
  difference() {
    union() {
      frame(h);
      translate([0, 0, h]) lip();
    }
    lip_recess();
    // Cable notch for the ring light at the top of the back wall.
    translate([-W / 2 + 25, D / 2 - wall / 2, h - 3]) cube([8, wall + 2, 6.1], center = true);
  }
}
module spacer() { tower(spacer_height); }
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

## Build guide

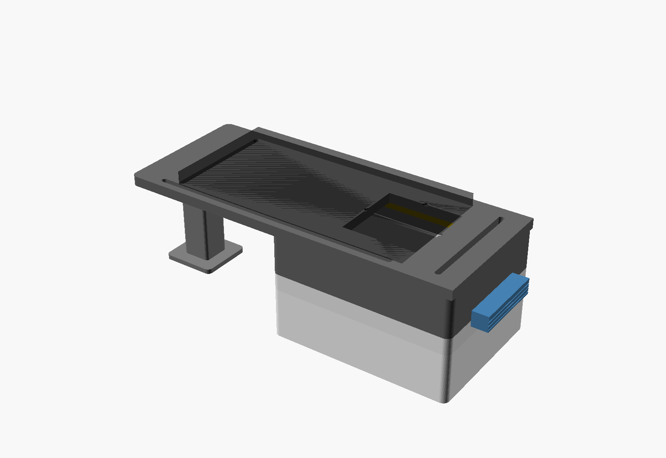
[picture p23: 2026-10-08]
rig/img/assembly.png

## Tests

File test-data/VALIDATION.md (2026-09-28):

# Validation run — wing-normalizer-0.2

Run date: 2026-09-27. All processing local; no image API used.

- 19/19 Node tests passed (`node tests/normalizer.test.js`).
- 36/36 real development images produced results in Chromium.
- Segmentation rules reported 2 GOOD, 34 REVIEW. This is a QC distribution,
  **not** 36 correct segmentations. Frames/uneven backgrounds sometimes produce
  incorrect masks; inspect overlays and correct masks before acceptance.
- Median preprocessing runtime: 609 ms in this run (hardware dependent,
  excludes decode and UI; source sizes range from publication crops to 9 MP).
- Browser checks passed: input, confirmation, accept, acceptance invalidation on
  flip, reset, same-image pair registration, clear, IndexedDB restore,
  re-acceptance, JSON export including mask runs. Identity mask IoU: 1.0.
- SHA-256 verified for every downloaded image/crop. Untouched landmark CSV MD5:
  `fd12bd4cfe2aa0e989472039497dfa34`, matching the Zenodo record.

For the controlled real-image perturbations, normalized mask IoU against the
baseline was 0.985–0.995 for rotations, 1.0 for translation, and 0.987–0.994 for
scale changes. A changed padding/background case fell to **0.612**: a known
failure caused by background differences / artificial composite boundaries.
All these perturbed cases reported REVIEW. These are consistency measurements,
not agreement against hand-labelled wing masks, and do not prove anatomical
correctness. Full results: `benchmark.json`, `real-invariance.json`.

Remaining scientific validation gaps: independently annotated contour ground
truth; independent captures of the same wing; controlled bee WIP/venation pairs;
calibrated orientation accuracy across genera; anterior/posterior detection.
No probabilities or successful biological pairing are inferred from these tests.

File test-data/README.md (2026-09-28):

# Entwicklungsdatensatz

36 lokal gespeicherte Wildbienen-Vorderflügelbilder bzw. veröffentlichte Panels:

- **18 originale PNGs** aus Molasy & Tofilski (Zenodo 19703357): drei Bombus-Arten,
  beide Geschlechter, linke/rechte Seiten, 3488 × 2616 px, schwankende Helligkeit,
  Abrieb, Artefakte und häufig abgeschnittene Basis. In `difficult/`.
- **18 Panels A–R** aus Spiesman et al. (2024), Fig S2 im S1-Supplement:
  Agapostemon, Bombus, Ceratina, Lasioglossum. Crops aus dem publizierten Raster,
  ohne Resize/Farbänderungen; Beschriftungen bleiben erhalten. Panel F zeigt
  einen weitgehend vollständigen Flügel (`venation/`), andere sind angeschnitten
  oder beschädigt (`difficult/`). Keine unabhängig wiederholten Aufnahmen.

Die Originalbilder wurden visuell als Kontaktübersicht geprüft. Die automatische
Maske muss trotzdem pro Bild kontrolliert werden. Besonders Bilder mit Rahmen,
Schrift, starker Hintergrundvariation oder angeschnittener Kontur können große
Hintergrundflächen einschließen; `REVIEW` bedeutet **nicht freigegeben**.
Eine positive GOOD-Regelbewertung ist ebenfalls keine biologische Validierung.

`metadata.json` enthält Quelle, Autor, Lizenz, Taxon, soweit dokumentiert
Geschlecht/Seite, unbekannte Herkunft als null, Bildtyp, Zitat, Datum, Prüfsumme,
Schwierigkeitsmerkmale und exakte Ableitung. Geschlecht F/M im Zenodo-Satz stammt
aus Dateinamen, nicht aus eigener taxonomischer Überprüfung. Die CSV mit allen
19 Landmark-Koordinaten bleibt unverändert als `landmarks-original.csv` erhalten.
Links/rechts desselben Tieres sind keine Wiederholungsaufnahmen desselben Flügels.

## Reproduktion

```bash
python3 scripts/fetch-test-data.py
# Danach S1 File über den in metadata.json dokumentierten PLOS-Link laden:
python3 scripts/extract-publication-panels.py /path/to/supplement.docx
```

Erster Befehl benötigt nur Python-Standardbibliothek und lädt 18 ZIP-Mitglieder
über Byte-Ranges statt 2,7 GB Gesamtdaten. Zweiter benötigt Pillow. Die Auswahl
ist deterministisch (drei Positionen je Art/Geschlecht). Lizenzen und Attribution
stehen in `LICENSES.md`. Keine Dateien aus Quellen mit unklarer Lizenz kopiert.

`benchmark.json` protokolliert Verarbeitung/QC und Laufzeiten aller Bilder;
**keine** Segmentierungsgenauigkeit, da kuratierte Ground-Truth-Masken fehlen.
`real-invariance.json` untersucht kontrollierte geometrische Varianten eines
publizierten Bildes. Hintergrund-Padding erzeugt zusätzliche künstliche
Bildgrenzen; solche Fehler bleiben im Bericht sichtbar. Dies ist kein Test
unabhängiger Wiederholungsaufnahmen und keine externe Validierung.

WIP-Recherche und ausgeschlossene Quellen sind in `wip/README.md` und
`rejected/sources.json` dokumentiert. Der Dryad-Datensatz mit echten binären
Referenzmasken war recherchierbar, die Downloads wurden aber serverseitig
abgelehnt. Es werden keine Referenzmasken oder realen WIP-Paare vorgetäuscht.

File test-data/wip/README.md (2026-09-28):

No suitable openly licensed **paired bee WIP / venation exposures** were located in this search.
The searched sources and exclusions are recorded in `../rejected/sources.json`.
Do not relabel venation panels or Diptera/wasp datasets as bee WIP data.
Dark-background synthetic RGB fixtures test geometry and preservation of channel values.
Same-image and perturbed-mask tests verify registration mechanics, not biological cross-modality accuracy.

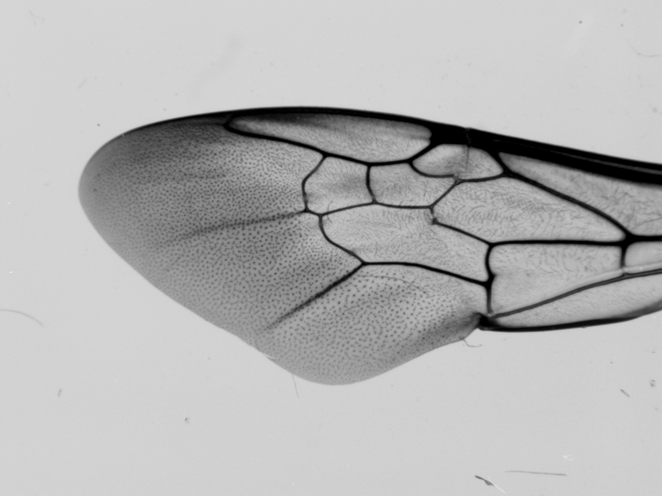
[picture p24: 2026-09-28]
test-data/difficult/terrestris-M-2023_1_1-L.dw.png

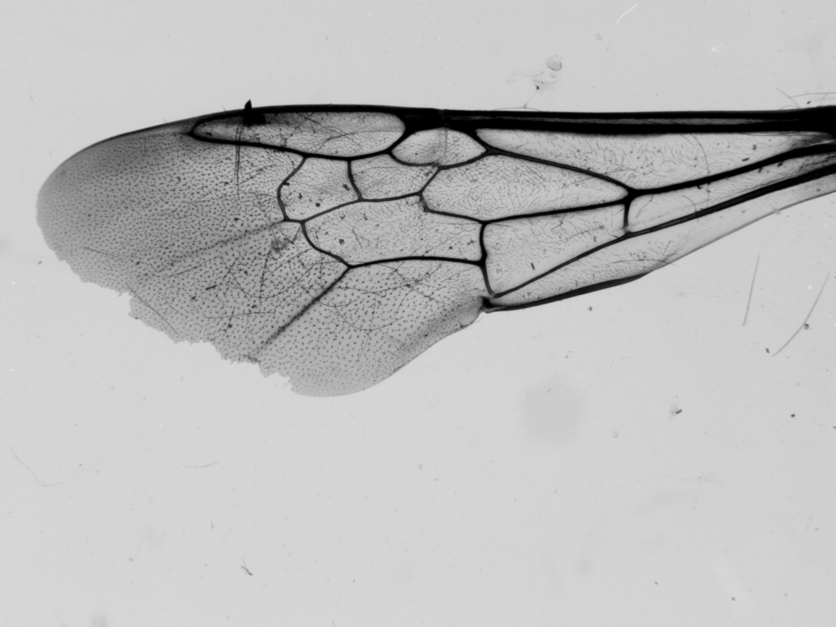
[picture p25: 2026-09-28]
test-data/difficult/cryptarum-M-BUM0435_SEG37A-R.dw.png

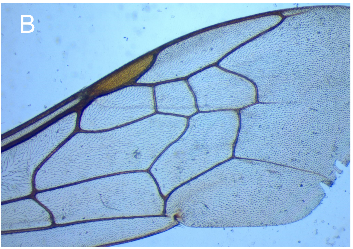
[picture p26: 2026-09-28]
test-data/difficult/Spiesman-S2-B-Agapostemon-texanus.png

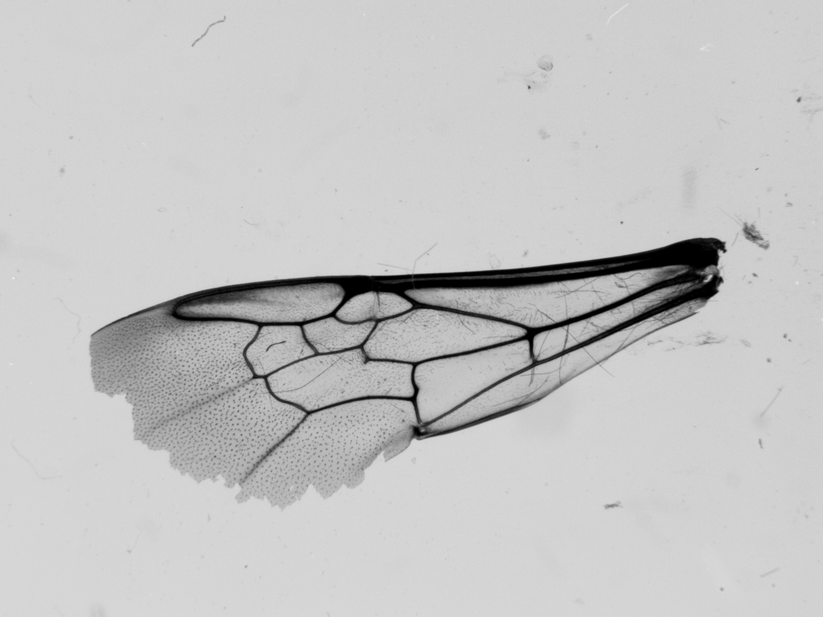
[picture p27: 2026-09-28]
test-data/difficult/cryptarum-F-BUM0463_SEG37A-R.dw.png

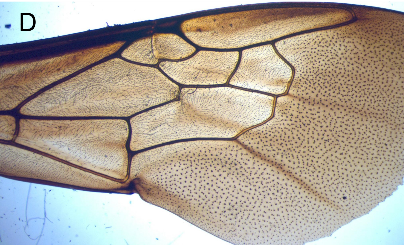
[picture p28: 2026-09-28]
test-data/difficult/Spiesman-S2-D-Bombus-griseocollis.png

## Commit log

2026-09-28 Add Wingmate analysis app with Markov walks, camera capture and PWA support
    [landmarks-original.csv]
2026-10-08 Fix grouped calibration and streamline review workflow
    Enforce reproducible model contracts and safe image features, update grouped development benchmarks, and simplify the documented UI issues. Include the user manual, pipeline audit, and printable capture rig.
    [base.stl, carrier.stl, carrier_wip.stl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]
2026-10-08 model update
    [BY-data.csv, BY-raw-coordinates.csv, DE-data.csv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]
